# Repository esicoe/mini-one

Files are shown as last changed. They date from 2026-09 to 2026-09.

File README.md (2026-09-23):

# mini-one: a high-power rocketry flight computer

<p align="center">
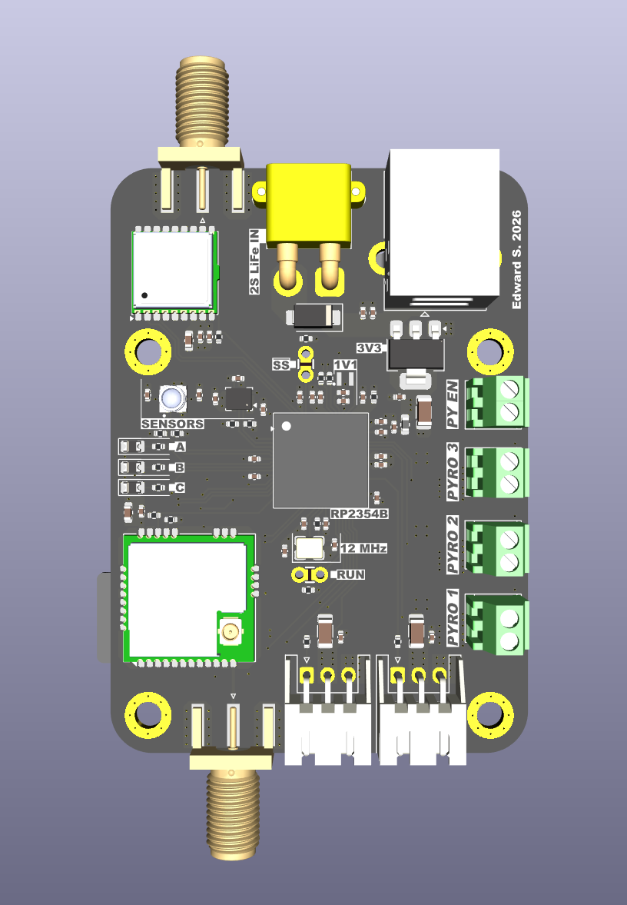
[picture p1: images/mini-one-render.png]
KiCad render of the mini-one flight computer
  
</p>

mini-one is a 50 x 70 mm flight computer for high-power rocketry airframes of 54 mm and up. It carries the
sensors, storage, GPS, LoRa telemetry, pyro channels and servo outputs for a flight steered by thrust vector
control (TVC), and it's the second generation of my avionics platform.

## Status

| Version | State |
|---|---|
| **v2, mini-one** (this repo) | Schematic and 4-layer layout done. Fabricated and assembled by JLCPCB (X-rays below). Next: bring-up, then firmware |
| **v1, two-board stack** | Built and bench-tested in June 2026. See [Earlier versions](#earlier-versions) |

## Hardware (v2)

| | |
|---|---|
| MCU | Raspberry Pi RP2354B (dual Arm Cortex-M33), 12 MHz crystal |
| IMU | ST LSM6DSV32X, 6-axis, up to 32 g |
| Barometer | Bosch BMP585 |
| GNSS | u-blox MAX-M10S, edge-mount SMA antenna |
| Telemetry | RAKwireless RAK3172 LoRa module (868/915 MHz), edge-mount SMA antenna |
| Storage | Winbond W25Q128 (128 Mbit) SPI NOR flash, plus microSD |
| Pyro | 3 channels on AO3400A MOSFETs, continuity LEDs, pyro bus armed by an external switch (PY EN) |
| Servos | 2 outputs on JST-XH connectors, for TVC |
| Power | 2S LiFePO4 battery on XT30, diode-OR'd with USB (SS54), AMS1117 3.3 V regulator |
| USB | USB-B |
| PCB | 4 layers (signal / ground / power / signal), 50 x 70 mm, 100 parts placed by JLCPCB |

The schematic is split into five hierarchical sheets: processor, power and interface, sensors and memory, RF,
and outputs. Everything is in [`pcb/`](pcb), and the Gerbers, BOM and pick-and-place files are in
[`manufacturing/`](manufacturing).

## Firmware (in progress)

The plan splits the work across the RP2354B's two cores:

- **Core 0:** a deterministic loop for sensor fusion and the flight state machine.
- **Core 1:** data logging, GNSS parsing and LoRa telemetry.
- The two cores pass data through a lock-free ring buffer, so logging and radio never stall the flight loop.

## X-ray inspection

JLCPCB X-rayed the assembled boards to check the solder joints under the QFN and the modules. Click an image
for full resolution.

<p align="center">
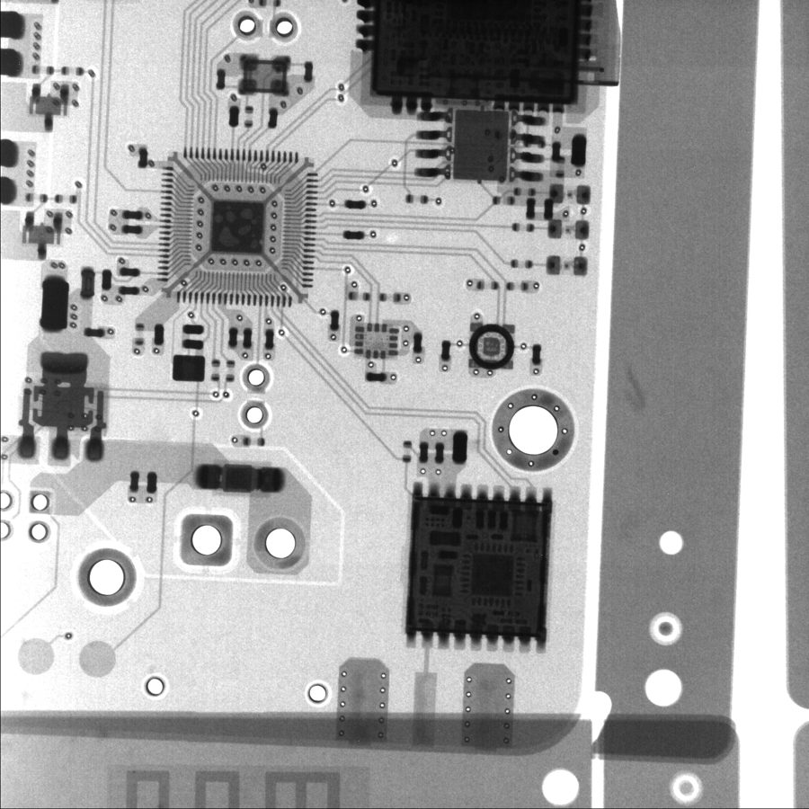
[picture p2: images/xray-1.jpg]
JLCPCB X-ray of the assembled board, image 1
  
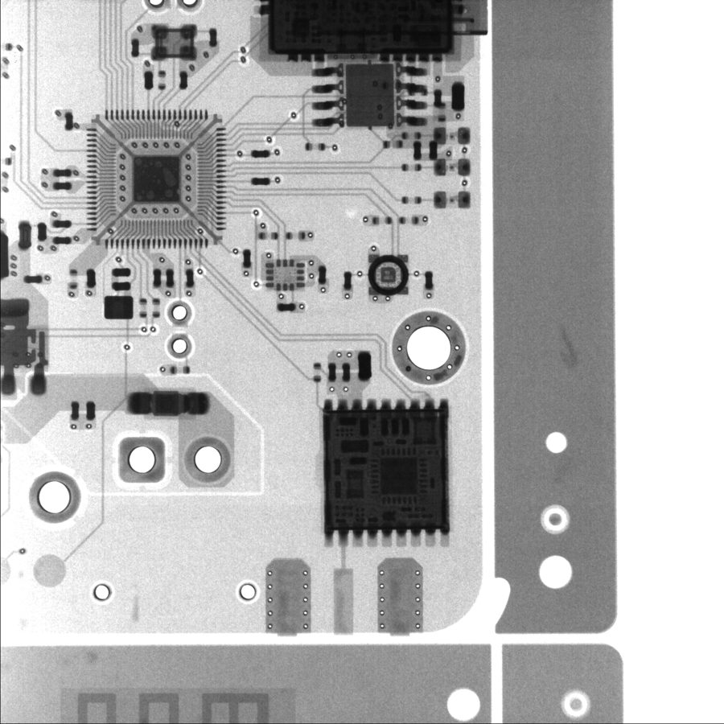
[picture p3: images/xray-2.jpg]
JLCPCB X-ray of the assembled board, image 2
  
</p>

## Earlier versions

### v1: two-board stack (June 2026)

<p align="center">
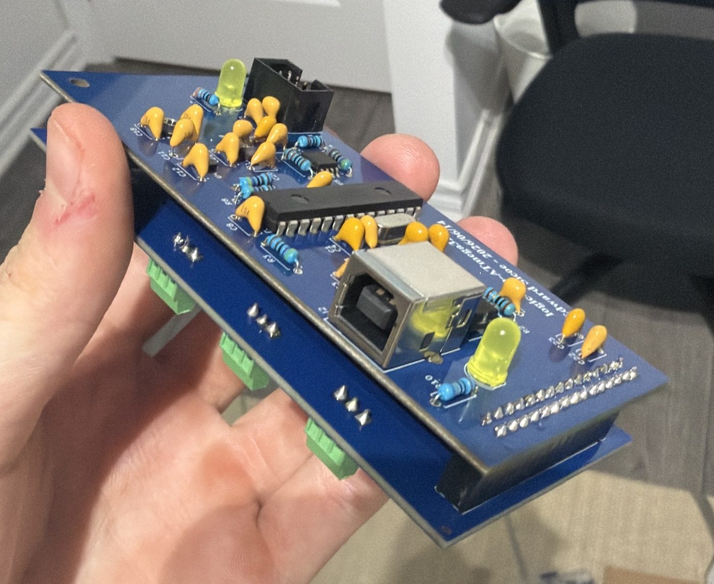
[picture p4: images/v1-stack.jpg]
The v1 logic board stacked on the v1 power board
  
</p>

v1 split the flight computer into a logic board stacked on a power board, joined by a board-to-board pin header.

- **Logic board** (`logic-pcb-ATmega328P`, 2026-06-14). An ATmega328P at 12 MHz with a CH340 USB-to-serial
  bridge on USB-B, a W25Q32 SPI NOR flash, an ISP header and status LEDs, mostly in through-hole parts. The
  firmware is bare-metal C written from the datasheets, with no Arduino libraries: drivers for UART at 250 kbaud,
  I2C (TWI) and the SPI flash. It's built with avr-gcc and flashed with avrdude over a USBtinyISP.
- **Power board** (`power-pcb v1.0`, 2026-06-02). XT30 battery input with a fuse, a 3.3 V buck converter, three
  5 V buck converters (one per servo output), three pyro channels with continuity LEDs, and an enable jumper.

<p align="center">
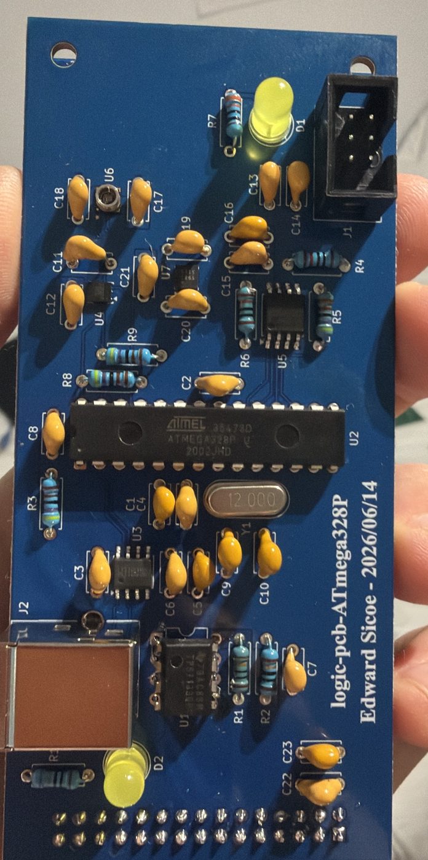
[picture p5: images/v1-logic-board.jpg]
v1 logic board
  
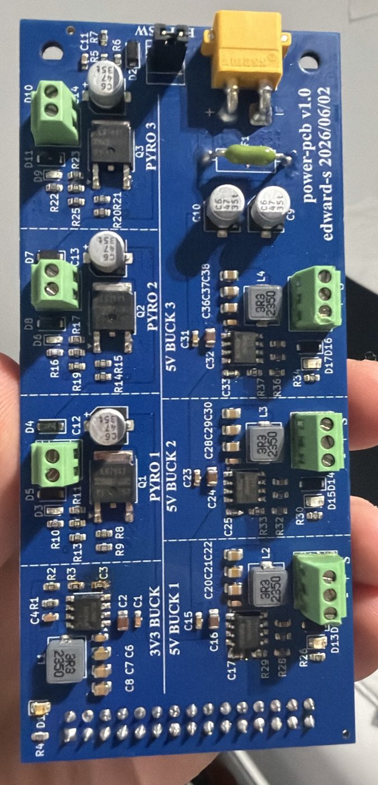
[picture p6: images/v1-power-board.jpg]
v1 power board
  
</p>

<p align="center">
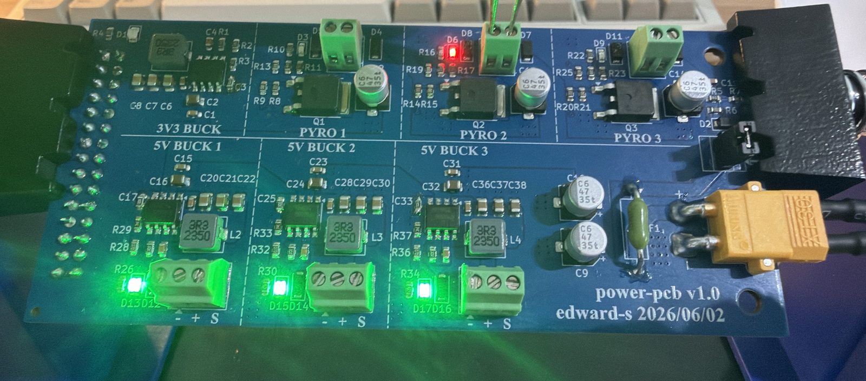
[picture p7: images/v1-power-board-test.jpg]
v1 power board powered on the bench
  
  <br><em>Power board on the bench: the three 5 V rails up (green) and a continuity check on PYRO 2 (red).</em>
</p>

Bring-up found two board-level bugs, and both were fixed by rework:

- A regulator enable pin that was wired wrong.
- A capacitor placed where a buck converter's frequency-setting resistor belonged.

### What changed from v1 to v2

| | v1 | v2 (mini-one) |
|---|---|---|
| Boards | Logic + power stack | One 4-layer board, 50 x 70 mm |
| MCU | ATmega328P (8-bit AVR) | RP2354B (dual Cortex-M33) |
| Radio and GNSS | Not on board | LoRa telemetry and u-blox GNSS |
| Assembly | Through-hole and SMD | 100 machine-placed SMD parts |

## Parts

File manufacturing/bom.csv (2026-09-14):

Designator | Footprint | Quantity | Value | LCSC Part #
C1, C10, C12, C13, C14, C17, C18, C19, C2, C21, C22, C27, C29, C34, C35, C36, C38, C4, C40, C41, C42, C43, C44, C7, C8 | 0402 | 25 | 100n | C307331
C11, C9 | 0402 | 2 | 15p | C1548
C15, C16, C20, C3, C5, C6 | 0402 | 6 | 4u7 | C23733
C23, C24, C25, C26, C28, C30, C31, C32, C33 | 1206 | 9 | 22u | C12891
C37 | 0402 | 1 | 1u | C52923
C39, C45, C46 | 0603 | 3 | 10u | C96446
D1, D2, D3 | 0805 | 3 | KT-0805Y | C2296
D4 | D_SMA | 1 | SS54 | C22452
D5, D6, D7 | 0603 | 3 | KT-0603R | C2286
FB1 | 0603 | 1 | GZ1608D601TF | C1002
J11 | microSD_External_Pin | 1 | MSD-1-A | C20619272
L1 | 0806_Polarized | 1 | 3u3 | C42411119
Q1, Q2, Q3 | SOT-23 | 3 | AO3400A | C20917
R1, R2, R9 | 0402 | 3 | 1k | C11702
R10, R14, R18, R21, R22, R29, R30 | 0402 | 7 | 4k7 | C25900
R11, R13, R15, R16, R19 | 0402 | 5 | 330R | C25104
R12, R17, R20 | 0603 | 3 | 2k7 | C13167
R23, R24, R25, R26, R27, R28, R31, R32, R33 | 0402 | 9 | 10k | C25744
R3, R4 | 0402 | 2 | 27R | C25100
R5, R6, R7 | 0402 | 3 | 220R | C25091
R8 | 0402 | 1 | 33R | C25105
U1 | QFN-80-1EP_10x10mm_P0.4mm_EP3.4x3.4mm | 1 | RP2354B | C39843328
U2 | SOT-223-3_TabPin2 | 1 | AMS1117-3.3 | C6186
U3 | BMP585 | 1 | BMP585 | C18184976
U4 | SOIC-8_5.3x5.3mm_P1.27mm | 1 | W25Q128JVSIQ | C97521
U5 | LGA-14_3x2.5mm_P0.5mm_LayoutBorder3x4y | 1 | LSM6DSV32XTR | C22461202
U6 | ublox_MAX | 1 | MAX-M10S | C4153167
U7 | RAK3172 | 1 | RAK3172-8-SM-NI | C5452091
Y1 | Crystal_SMD_3225-4Pin_3.2x2.5mm | 1 | ABM8-272-T3 | C20625731

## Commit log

2026-09-09 made repo
    [RF.kicad_sch, mini-one-pcb.kicad_pcb, mini-one-pcb.kicad_sch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]
2026-09-14 PCB update
    [RF.kicad_sch, bom.csv, designators.csv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]
